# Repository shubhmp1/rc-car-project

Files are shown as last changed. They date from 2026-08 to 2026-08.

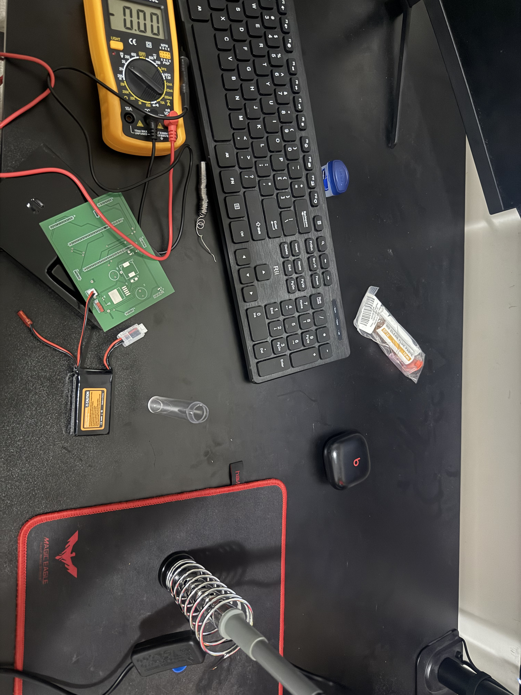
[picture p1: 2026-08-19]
media/build-photos/IMG_1891.jpg

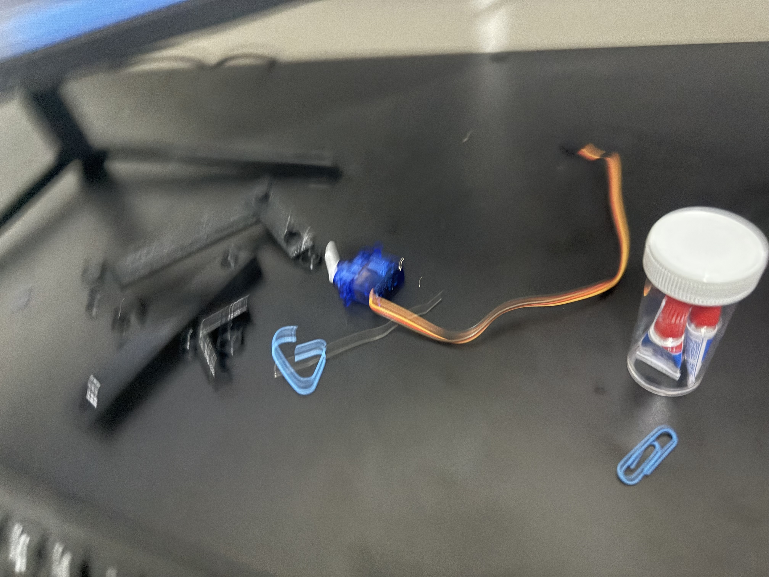
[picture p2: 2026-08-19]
media/build-photos/IMG_1993.jpg

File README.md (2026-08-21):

# Dual-ESP32 RC Car: Custom PCB, 3D-Printed Chassis, With Standard Driving and Auto-Driving Modes

A fully custom-built RC car, designed from scratch: hand-routed PCBs, 3D-printed chassis and wheels, and firmware for two ESP32s talking over nRF24L01 RF. Built solo from schematic to final assembly.

Final car
<!-- swap in your best final-photo filename above -->

---

## Why I built this

Going into engineering, I felt lost, since there are so many different paths (mechanical, electrical, software, embedded) and so much to learn that it was hard to know where to actually start. So instead of trying to learn everything separately, I picked one project that would force me to touch all of it, end to end: CAD, PCB design, firmware, RF communication, sensors, and 3D printing.

Every single one of those was a first for me. I'd never designed a mechanical assembly, never laid out a PCB, never written embedded firmware for a microcontroller, never worked with RF modules or these sensors before this project. I learned all of it here, from scratch, because I wanted proof (mostly to myself) that I could pick up any of these disciplines if I actually committed to it.

And I picked an RC car specifically because outside of computers, cars are what I love most. This project let me combine both.

---

## Demo

**Video:** _[YouTube link coming soon]_

<!-- once uploaded, replace with: [![Watch the demo](docs/images/thumbnail.jpg)](https://youtube.com/your-link) -->

---

## What it does

The car runs on two ESP32s (one in the handheld remote, one on the car), communicating over **nRF24L01 RF**. The remote has a joystick, a TFT display showing speed/mode/sensor data, and three mode buttons with illuminated LEDs.

**Modes:**
- **Standard Driving Mode (done):** manual driving. Joystick controls throttle (with exponential curve, deadzone, and slew-rate limiting) and steering.
- **Auto-Driving Mode (done):** a front-facing ToF sensor slows/stops the car as it approaches obstacles, while two IR line sensors keep it centered between track markers (tested using black tape "lanes" on the ground).
- **AI Gesture Mode (planned, not built):** connect the car to a PC over WiFi and drive it using hand-gesture recognition from a model running locally. Documented as a future addition in the [build notes](docs/Rough_Dev_Journal_And_Notes.docx).

## Hardware

Full parts list and exact values are in the [Specs](#specs) table below. At a high level: two ESP32s (one per board), custom Altium PCBs for both the car and remote, a brushed DC gear motor through an L298N driver, servo-based Ackermann steering, a ToF sensor for obstacle detection, IR sensors for line tracking, and a 3D-printed chassis/wheel set iterated across several print revisions.

## Specs

| Spec | Value |
|---|---|
| MCU | 2× ESP32 (one in the remote, one on the car) |
| Communication | nRF24L01, 250kbps, with ACK-payload telemetry back to the remote |
| Motor | GA12-N20, 6V, 200RPM, all-metal gearbox, 3mm shaft |
| Motor Driver | L298N |
| Steering | Standard positional servo, Ackermann-style linkage |
| Joystick | PS2-style dual-axis breakout module |
| Display | Waveshare 2.4" SPI LCD, 240×320, 65K color |
| Obstacle Sensor | VL53L1X ToF (long-range mode) |
| Line Sensors | 2× TCRT5000 IR reflectance sensors |
| Chassis / Wheels | 3D-printed (PLA), iterated through multiple print revisions |
| PCBs | Custom, designed in Altium (one for the car, one for the remote) |

## How it works

**Communication:** the remote and car each run their own ESP32, talking over an nRF24L01 RF link. Every ~50ms the remote sends a small packet containing motor speed, steering angle, current mode, and (in auto-driving mode) an armed flag and target cruise speed. The car replies on the same exchange using nRF24's ACK-payload feature, sending back live sensor readings (IR states, ToF distance, current speed, and status flags) so the remote's display can show what the car is actually doing in real time, not just what was last commanded.

**Standard driving mode:** joystick input is normalized, run through a small deadzone, shaped with an exponential curve (so small stick movements give fine control, large movements ramp up quickly), and slew-rate limited before being sent, so the motor doesn't jump instantly between speeds or slam through zero when reversing.

**Auto-driving mode:** the car ignores direct joystick input entirely and drives itself off two inputs: two IR sensors on the underside detect track-edge markers and nudge steering back toward center when either sensor sees the line, and a ToF sensor up front continuously calculates a dynamic safe-stopping distance based on the car's current speed (faster speed → longer required stopping distance), slowing or fully stopping the car as it approaches obstacles. The remote is used first to set a target cruise speed, then the car handles both throttle and steering on its own within that mode.

**Displays and modes:** the remote's screen (driven over SPI) shows different HUDs depending on the active mode, live speed/direction/steering in standard mode, or live sensor telemetry and braking status in auto-driving mode, so you can see what the car's sensors are reading even while it's driving itself.

Full firmware for both boards is in [`firmware/`](firmware/).

## Repo structure

```
├── docs/
│   ├── Rough_Dev_Journal_And_Notes.docx   ← full unfiltered build log/notes
│   └── images/                             ← screenshots & progress photos
├── hardware/
│   ├── cad/           ← final STEP files (chassis, wheels, mounts)
│   ├── pcb/            ← Altium projects + gerbers for both boards
│   │   ├── RC_Car/
│   │   └── RC_Remote/
│   └── 3d-print/       ← .3mf print files (all iterations kept)
├── firmware/
│   ├── Car/            ← car-side Arduino sketch
│   └── RC/             ← remote-side Arduino sketch
├── media/
│   ├── build-photos/   ← progress photos throughout the build
│   └── final-photos/   ← finished car
└── README.md
```

## Build photos

A few shots from along the way. See [`media/build-photos`](media/build-photos) for the full set.

<!-- Consider dropping 2-3 of your favorite in-progress photos inline here, e.g.: -->
<!-- ![Soldering the PCB](media/build-photos/photo1.jpg) -->

## Lessons learned

Pulled from the full [build journal](docs/Rough_Dev_Journal_And_Notes.docx), short version:

- **Bluetooth's signal backlog caused an infinite loop** in early remote-to-car communication. Switched to nRF24 RF instead, which was far more reliable for this use case.
- **PWM-driven motor control glitched under per-loop calculation load:** the ESP32 couldn't keep up doing full throttle/LED calculations every cycle. Fixed by throttling the calculation rate (~25Hz instead of 100Hz) and reducing floating-point math in the hot path.
- **Motor driver testing with a bare BJT/MOSFET failed:** couldn't draw enough current. Confirmed the need for a proper motor driver IC (L298N) rather than a hand-built switching circuit.
- **A GND/5V short during power-supply assembly** was a good reminder to double- and triple-check polarity before powering up a new board, since one bad connection can take out multiple components at once.
- **Hand-soldering fine-pitch parts (buck converters, ESP32 headers) without hot air or flux paste** led to several repeated attempts and a few damaged boards/pins, showing the value of having the right soldering tools before starting dense PCB assembly.
- **PCB trace width mattered more than expected:** signal traces at 0.2mm, power at 0.5mm, and battery lines at 0.8mm, with careful separation between noisy traces (motor lines) and sensitive ones (RF module) to avoid interference.
- **3D-printed part tolerances needed iteration:** the first wheel rim print was a couple mm undersized on outer diameter despite correct shaft/width dimensions, so it took a second revision to dial in.
- **Debugging RF instability came down to reworked solder joints:** several intermittent sensor/module failures traced back to damaged pins from desoldering, ultimately solved by fresh ESP32 boards rather than continuing to chase individual pin issues.

## Status

Core build (standard driving mode + auto-driving mode) is complete and working. AI gesture mode is a planned future addition; see the notes for early thinking on that.

## License

[MIT](LICENSE). Feel free to reference, fork, or build on this. Attribution appreciated.

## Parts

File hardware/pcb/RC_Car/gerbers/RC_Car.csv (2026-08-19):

Line # | Name | Description | Designator | Revision ID | Revision State | Revision Status | Quantity | Manufacturer 1 | Manufacturer Part Number 1 | Manufacturer Lifecycle 1 | Supplier 1 | Supplier Part Number 1 | Supplier Unit Price 1 | Supplier Subtotal 1
1 | EEUFM1E681 | 680F 25V Aluminum Electrolytic Capacitors Radial, Can 5000 Hrs @ 105C | C1 |  | Not managed |  | 1
2 | EEU-FC1E471 | Capacitor Polarised | C2 |  | Not managed |  | 1
3 | Capacitor 100 nF +/-10% 50 V 0603 | Chip Capacitor, 100 nF, +/- 10%, 50 V, 0603 (1608 Metric) | C3, C4, C5 | CMP-001-00017-6 | Draft | Up to date | 3 | KYOCERA AVX | 06035C104KAT2A | Volume Production | RS (Formerly Allied Electronics) | 06035C104KAT2A | 0.02768 | 0.08305
4 | CDBA540-HF | Schottky Diode | D1 |  | Not managed |  | 1
5 | TLMS1100-GS08 | Red Led, 20mA, 2.1 V, -40 to 100 degC, 2-Pin SMD (0603), RoHS, Tape and Reel | D2 | CMP-007-00030-2 | Draft | Up to date | 1 | Vishay | TLMS1100-GS08 | Obsolete
6 | ESP32 Left Header | 20 Position Receptacle Connector 0.100 (2.54mm) Through Hole Gold | J1 |  | Not managed |  | 1
7 | ESP32 Right Header | 20 Position Receptacle Connector 0.100 (2.54mm) Through Hole Gold | J2 |  | Not managed |  | 1
8 | nRF24 Signals | Headers & Wire Housings .100 Tiger Buy Socket Strip, Square Tail | J3 |  | Not managed |  | 1
9 | nRF24 Power | SSQ Series .100 Tiger Buy™ Socket Strip, Square Tail | J4 |  | Not managed |  | 1
10 | B2B-PH-K-S(LF)(SN) | Male Header, Pitch 2 mm, 1 x 2 Position, Height 6 mm, Tail Length 3.4 mm, -25 to 85 degC, RoHS, Bulk | J5 | CMP-2000-05162-1 | Released | Up to date | 1 | JST | B2B-PH-K-S(LF)(SN) | Volume Production | Arrow Electronics | B2B-PH-K-S(LF)(SN) | 0.14118 | 0.14118
11 | L298N | Headers & Wire Housings .100 Tiger Buy Socket Strip, Square Tail | J6 |  | Not managed |  | 1
12 | Servo Motor | 3 Position Receptacle Connector 0.100 (2.54mm) Through Hole, Right Angle Tin | J7 |  | Not managed |  | 1
13 | Tof Sensor | Connector | J8 |  | Not managed |  | 1
14 | IR Sensor Left | 3 Position Receptacle Connector 0.100 (2.54mm) Through Hole, Right Angle Tin | J9 |  | Not managed |  | 1
15 | IR Sensor Right | 3 Position Receptacle Connector 0.100 (2.54mm) Through Hole, Right Angle Tin | J10 |  | Not managed |  | 1
16 | DR127-220-R | 22µH Shielded Wirewound Inductor 4A 39.1mOhm Nonstandard | L1 |  | Not managed |  | 1
17 | RC0603JR-13150RL |  | R1 | CMP-2000-04317-1 | Released | Up to date | 1 | Yageo Group | RC0603JR-13150RL | Volume Production | Mouser | 603-RC0603JR-13150RL | 0.13841 | 0.13841
18 | Power Switch |  | SW1 |  | Not managed |  | 1
19 | LM2596S-5.0 | SIMPLE SWITCHER® 4.5V to 40V, 3A Low Component Count Step-Down Regulator | U1 |  | Not managed |  | 1

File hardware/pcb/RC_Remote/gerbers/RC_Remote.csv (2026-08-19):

Line # | Name | Description | Designator | Revision ID | Revision State | Revision Status | Quantity | Manufacturer 1 | Manufacturer Part Number 1 | Manufacturer Lifecycle 1 | Supplier 1 | Supplier Part Number 1 | Supplier Unit Price 1 | Supplier Subtotal 1
 | EEUFM1E681 | 680F 25V Aluminum Electrolytic Capacitors Radial, Can 5000 Hrs @ 105C | C1 |  | Not managed |  | 1
 | EEU-FC1E471 | Capacitor Polarised | C2 |  | Not managed |  | 1
 | Capacitor 100 nF +/-10% 50 V 0603 | Chip Capacitor, 100 nF, +/- 10%, 50 V, 0603 (1608 Metric) | C3, C4 | CMP-001-00017-6 | Draft | Up to date | 2 | KYOCERA AVX | 06035C104KAT2A | Volume Production | RS (Formerly Allied Electronics) | 06035C104KAT2A | 0.02768 | 0.05536
 | CDBA540-HF | Schottky Diode | D1 |  | Not managed |  | 1
 | TLMS1100-GS08 | Red Led, 20mA, 2.1 V, -40 to 100 degC, 2-Pin SMD (0603), RoHS, Tape and Reel | D2 | CMP-007-00030-2 | Draft | Up to date | 1 | Vishay | TLMS1100-GS08 | Obsolete
 | ESP32 Left Header | 20 Position Receptacle Connector 0.100 (2.54mm) Through Hole Gold | J1 |  | Not managed |  | 1
 | ESP32 Right Header | 20 Position Receptacle Connector 0.100 (2.54mm) Through Hole Gold | J2 |  | Not managed |  | 1
 | nRF24 Signals | Headers & Wire Housings .100 Tiger Buy Socket Strip, Square Tail | J3 |  | Not managed |  | 1
 | nRF24 Power | SSQ Series .100 Tiger Buy™ Socket Strip, Square Tail | J4 |  | Not managed |  | 1
 | TFT Display | Headers & Wire Housings .100 Tiger Buy Socket Strip, Square Tail | J5 |  | Not managed |  | 1
 | Joystick | Headers & Wire Housings .100 Tiger Buy Socket Strip, Square Tail | J6 |  | Not managed |  | 1
 | B2B-PH-K-S(LF)(SN) | Male Header, Pitch 2 mm, 1 x 2 Position, Height 6 mm, Tail Length 3.4 mm, -25 to 85 degC, RoHS, Bulk | J7 | CMP-2000-05162-1 | Released | Up to date | 1 | JST | B2B-PH-K-S(LF)(SN) | Volume Production | Arrow Electronics | B2B-PH-K-S(LF)(SN) | 0.14118 | 0.14118
 | DR127-220-R | 22µH Shielded Wirewound Inductor 4A 39.1mOhm Nonstandard | L1 |  | Not managed |  | 1
 | MFR-25FBF52-47R5 | Axial Resistor, 47.5 Ohm, +/- 1%, 0.25 W, -55 to 155 degC, 2-Pin THD, RoHS, Bulk | R1, R2, R3 | CMP-009-00058-4 | Draft | Up to date | 3 | Yageo Group | MFR-25FBF52-47R5 | Volume Production | Arrow Electronics | MFR-25FBF52-47R5 | 0.07336 | 0.22007
 | RC0603JR-13150RL |  | R4 | CMP-2000-04317-1 | Released | Up to date | 1 | Yageo Group | RC0603JR-13150RL | Volume Production | Mouser | 603-RC0603JR-13150RL | 0.13841 | 0.13841
 | B3W-9002-Y1N | SWITCH TACTILE SPST-NO 0.05A 24V | SW1, SW2, SW3 | CMP-08834-000016-1 | New From Design | Up to date | 3 | Omron | B3W-9002-Y1N | Volume Production | Mouser | 653-B3W-9002-Y1N | 5.9 | 17.69
 | Power Switch |  | SW4 |  | Not managed |  | 1
 | LM2596S-5.0 | SIMPLE SWITCHER® 4.5V to 40V, 3A Low Component Count Step-Down Regulator | U1 |  | Not managed |  | 1

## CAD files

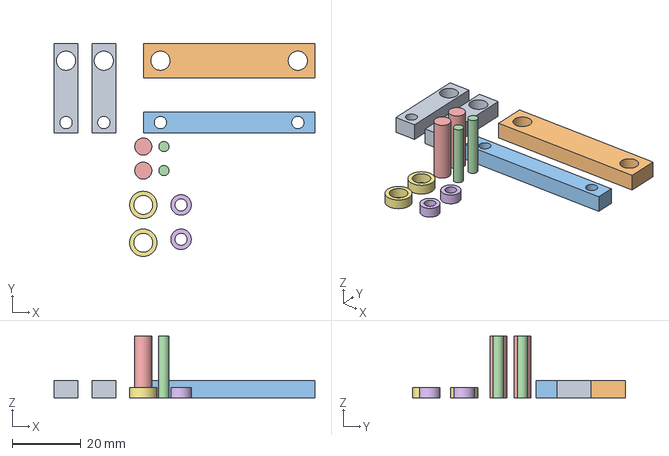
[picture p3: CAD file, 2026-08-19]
hardware/cad/Steering_Mech_V2.stp
76.0 x 62.0 x 18.0 mm

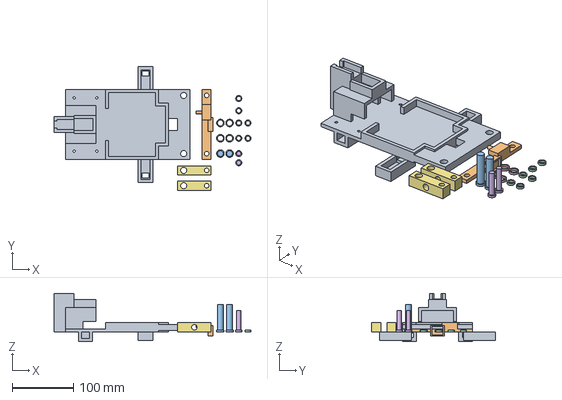
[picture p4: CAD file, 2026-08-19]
hardware/cad/Car_Chassis_V7.stp
322.0 x 202.0 x 79.0 mm

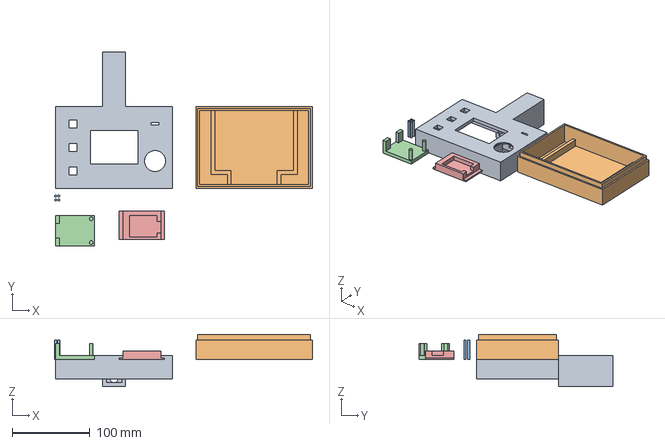
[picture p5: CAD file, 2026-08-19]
hardware/cad/Remote_Cad_V10.stp
331.5 x 249.0 x 67.0 mm

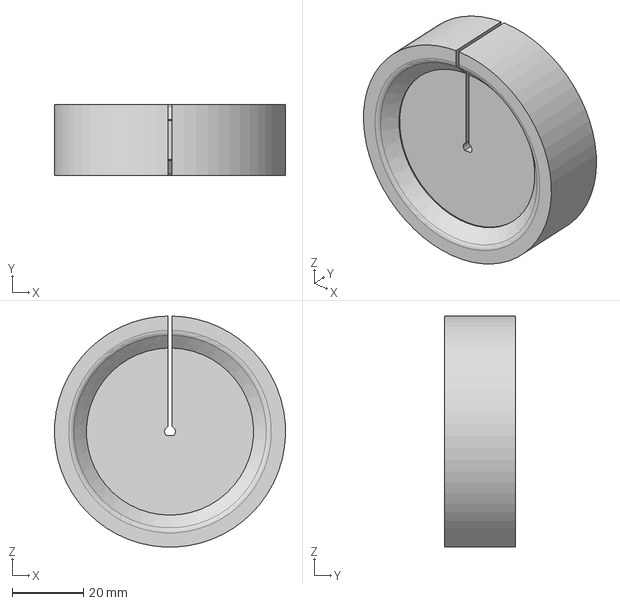
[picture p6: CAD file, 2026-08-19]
hardware/cad/RC_Car_Wheel_Rim_V3.stp
65.0 x 20.0 x 65.0 mm

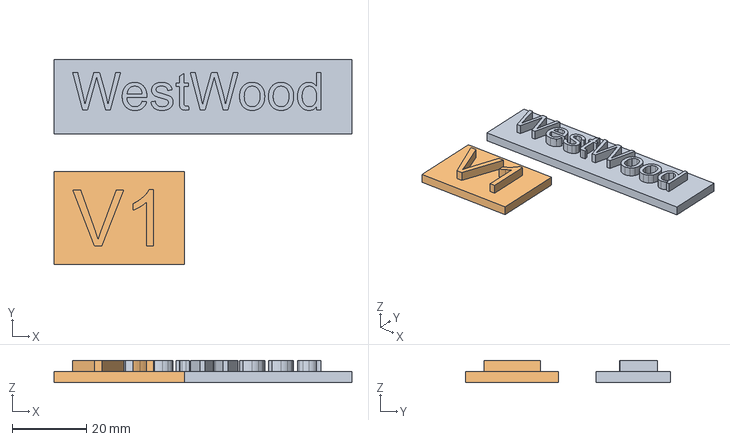
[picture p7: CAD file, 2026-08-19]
hardware/cad/Sign_V2.stp
80.0 x 55.0 x 6.00 mm

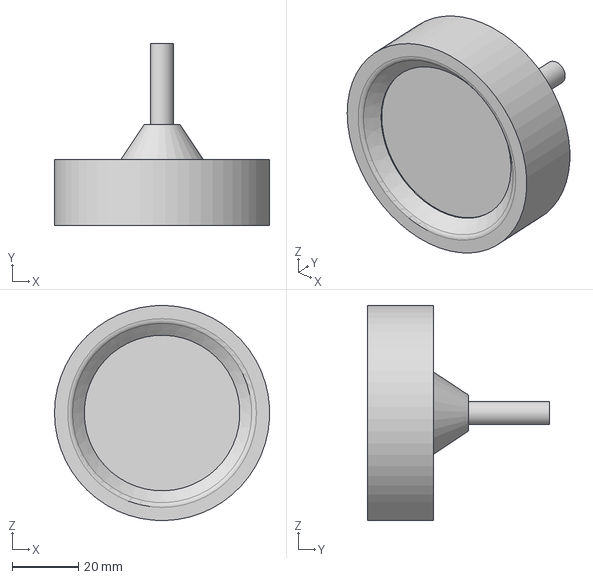
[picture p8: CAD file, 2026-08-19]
hardware/cad/RC_Car_Front_Wheel_Rim_V3.stp
64.9 x 55.0 x 65.0 mm

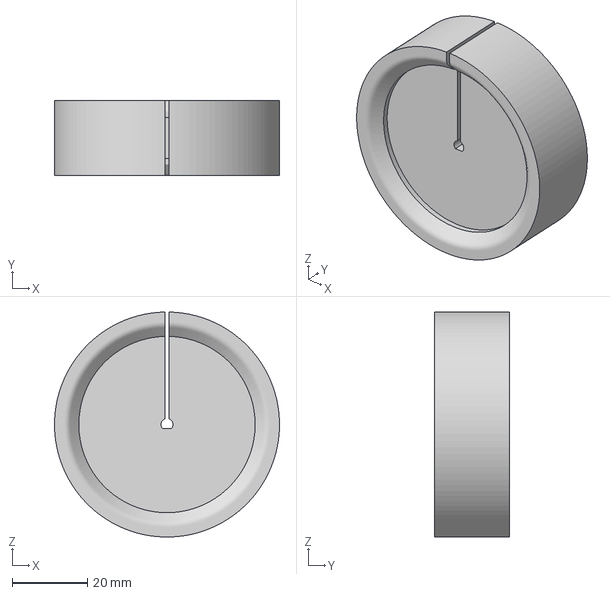
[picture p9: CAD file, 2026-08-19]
hardware/3d-print/RC_Car_Wheel_Rim.3mf
60.0 x 20.0 x 60.0 mm

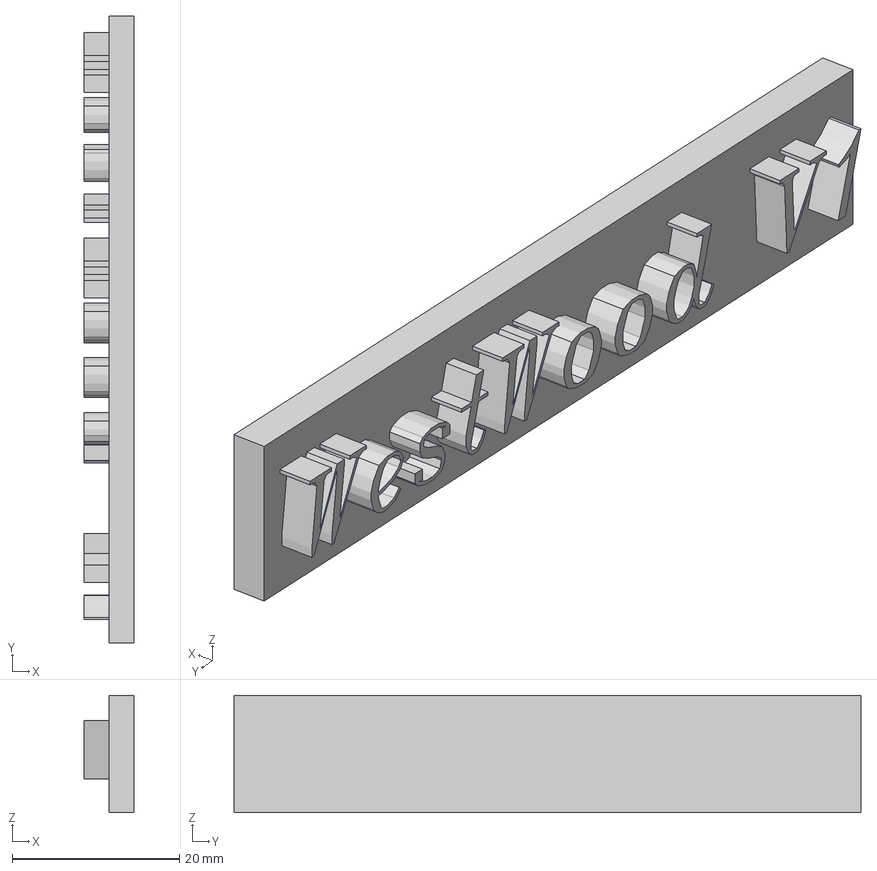
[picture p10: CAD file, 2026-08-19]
hardware/3d-print/Sign.3mf
6.00 x 75.0 x 14.0 mm

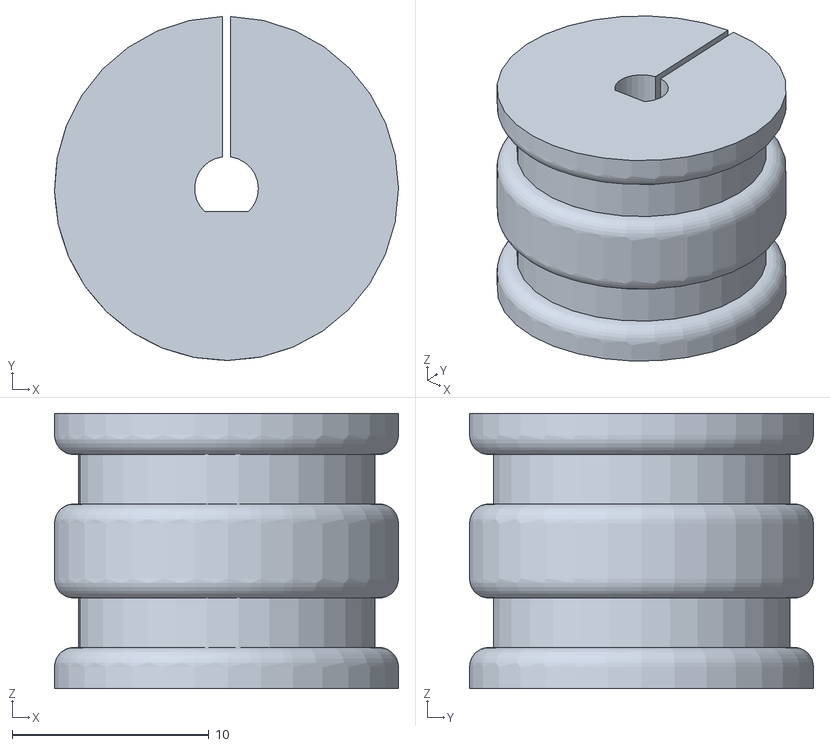
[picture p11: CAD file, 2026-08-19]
hardware/3d-print/double_wheel_14.stl
17.5 x 17.5 x 14.0

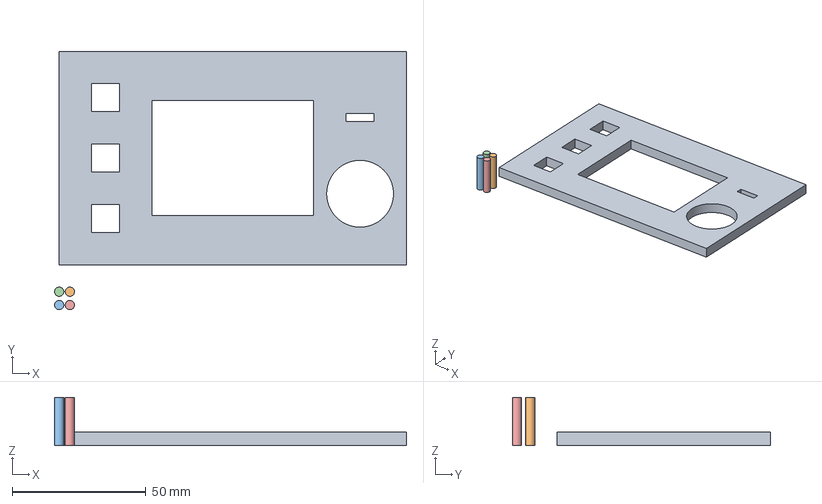
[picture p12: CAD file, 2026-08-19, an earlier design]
hardware/3d-print/Remote_Cad_V3.3mf
131.8 x 96.8 x 18.0 mm

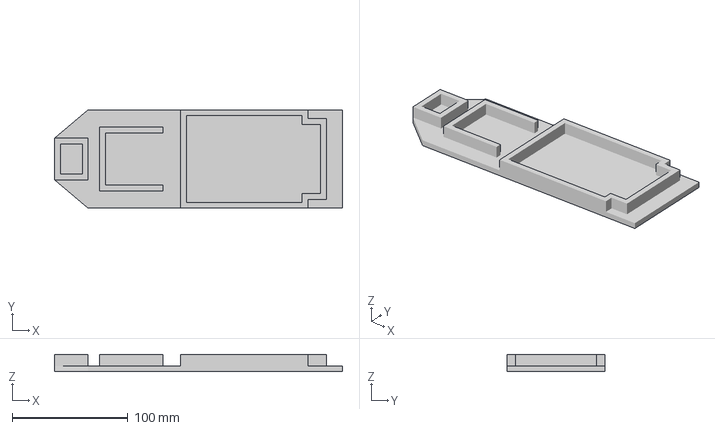
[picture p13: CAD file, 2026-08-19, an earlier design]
hardware/3d-print/Car_Chassis_V1.3mf
249.0 x 85.0 x 15.0 mm

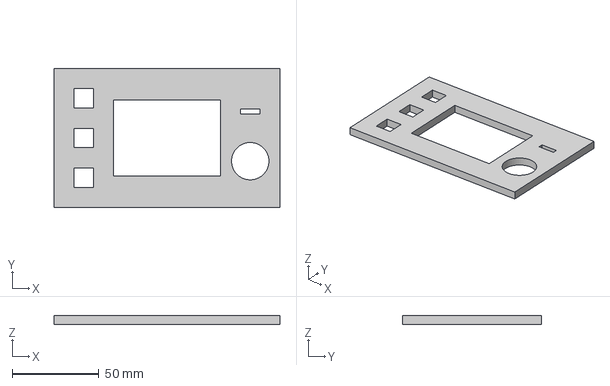
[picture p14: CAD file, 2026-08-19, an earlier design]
hardware/3d-print/Remote_Cad_V2.3mf
130.0 x 80.0 x 5.00 mm

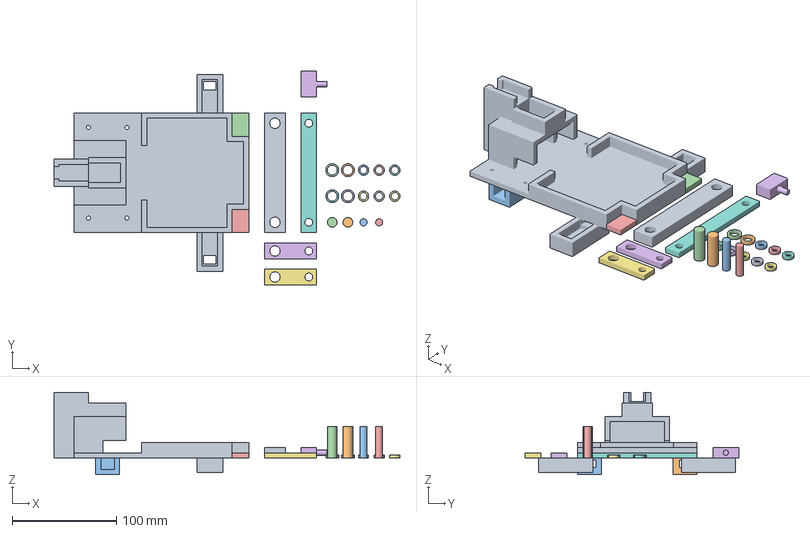
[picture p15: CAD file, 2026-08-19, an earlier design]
hardware/3d-print/Car_Chassis_V5.3mf
332.0 x 205.0 x 79.0 mm

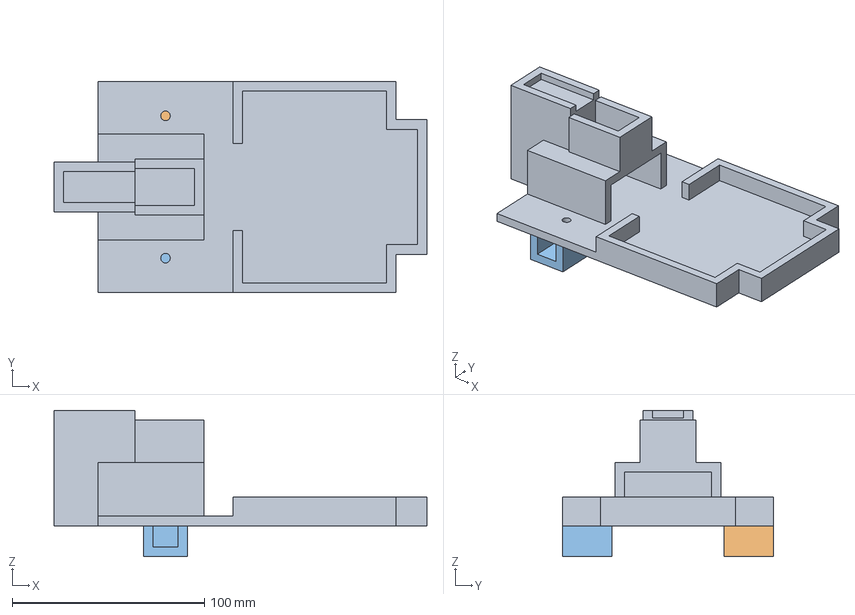
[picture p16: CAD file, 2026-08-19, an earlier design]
hardware/3d-print/Car_Chassis_V2.3mf
194.0 x 110.0 x 76.0 mm

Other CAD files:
hardware/3d-print/Car_Chassis_V8.3mf
hardware/3d-print/Remote_Cad_V11.3mf
hardware/3d-print/Steering_Mech_V3.3mf
hardware/3d-print/Steering_Mech_V1.3mf
hardware/3d-print/Car_Chassis_V3.3mf
hardware/3d-print/Car_Chassis_V4.3mf
hardware/3d-print/Car_Chassis_V6.3mf
hardware/3d-print/Car_Chassis_V7.3mf
hardware/3d-print/RC_Car_Front_Wheel_Rim_V1.3mf
hardware/3d-print/RC_Car_Front_Wheel_Rim_V2.3mf
hardware/3d-print/RC_Car_Front_Wheel_Rim_V3.3mf
hardware/3d-print/RC_Car_Wheel_Rim_V2.3mf
hardware/3d-print/RC_Car_Wheel_Rim_V3.3mf
hardware/3d-print/Remote_Cad_V1.3mf
hardware/3d-print/Remote_Cad_V10.3mf
hardware/3d-print/Remote_Cad_V4.3mf
hardware/3d-print/Remote_Cad_V5.3mf
hardware/3d-print/Remote_Cad_V6.3mf
hardware/3d-print/Remote_Cad_V7.3mf
hardware/3d-print/Remote_Cad_V8.3mf
hardware/3d-print/Remote_Cad_V9.3mf
hardware/3d-print/Sign_V2.3mf
hardware/3d-print/Steering_Mech_V2.3mf

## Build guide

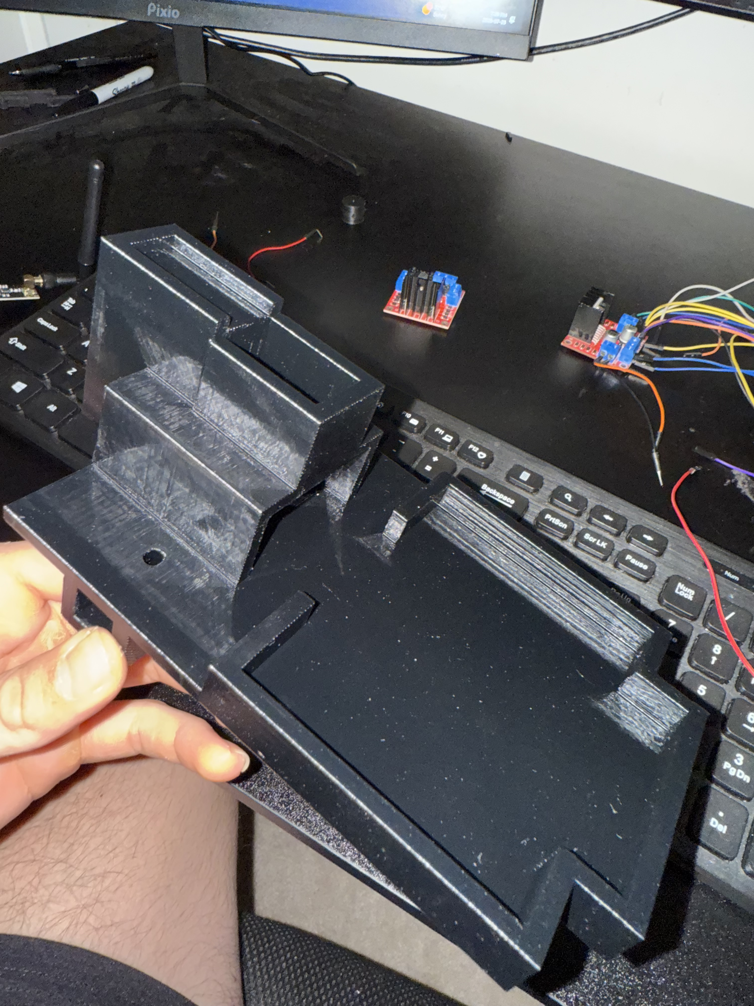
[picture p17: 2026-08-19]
media/build-photos/IMG_1975.jpg

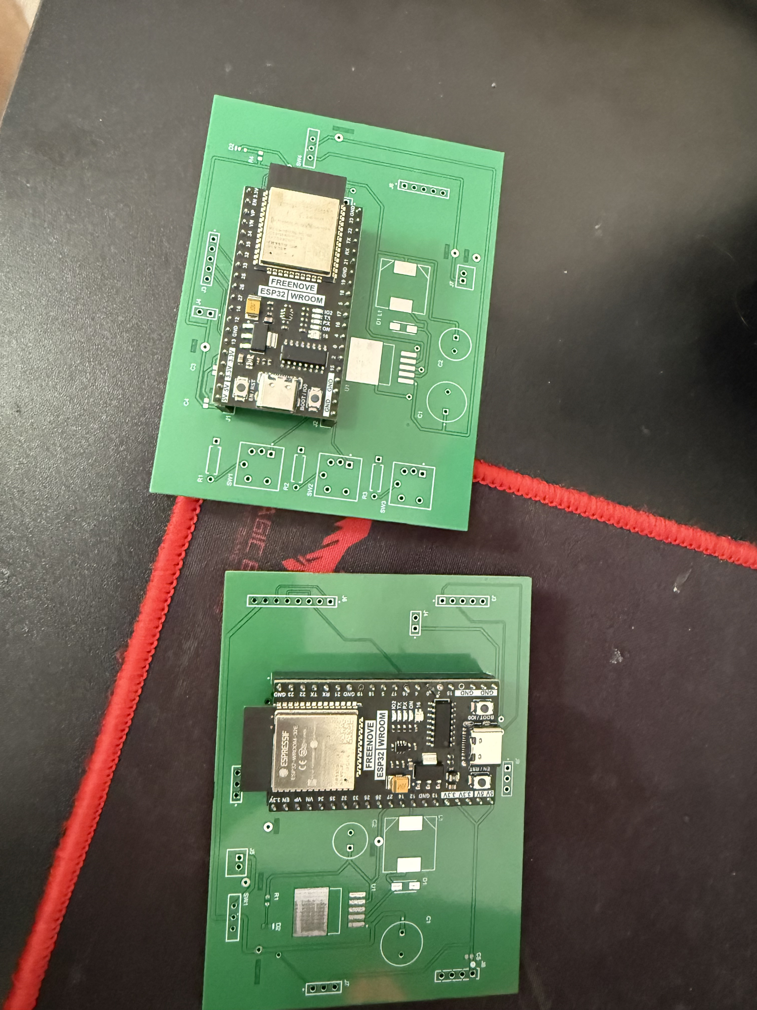
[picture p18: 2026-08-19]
media/build-photos/IMG_1922.jpg

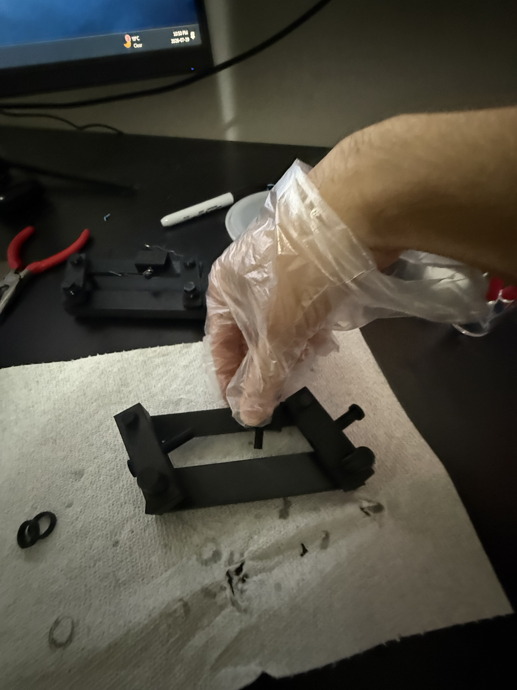
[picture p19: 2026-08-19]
media/build-photos/IMG_2006.jpg

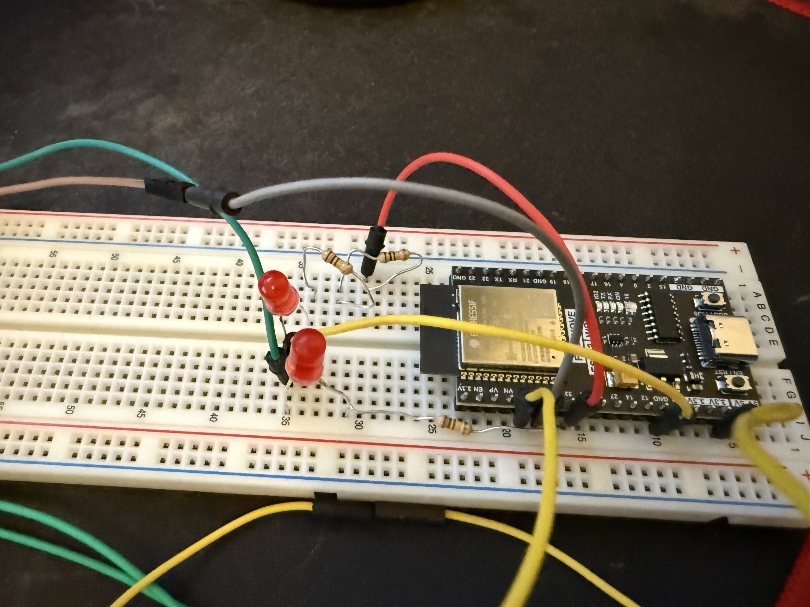
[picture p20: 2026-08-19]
media/build-photos/IMG_1554.jpg

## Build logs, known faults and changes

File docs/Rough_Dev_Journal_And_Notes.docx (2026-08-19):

Two ESP-32 With WIFI/BLUETOOTH/RF CONNECTIVITY

- Turning will be done, by simple servo motor changing direction in front, could possibly do pulse width modulation I do not know exactly how the angles on them work to make micro ajudsments, I would use differential but not required for this simple of design.
- Making an h-bridge PCB to use a more powerful battery to a good motor, also use pulse width modulation to allow the motor to have a variety of speeds
- If i use a bigger battery, im gonna have to make power supply PCB to the esp32
- ESP-32 going to use a communication protocol, thru wifi/bluetooth, from controller to car
- The rc can have the joystick, a button for honk, a screen for speed, a screen for battery percentage.

I wanna eventually make it so I can connect a camera to it, i can sit in my room then use a model to move it based on something the models detects me do, like put specific hand geistures or something. This would require me to do a WEB server, and me locally running a python script for the model

- Im gonna have to CAD the the controller and car, preferably make it like an M8.

Notes:

- For the joystick keep pins to left, so bottom right will have 4095.
- Servo motor right 0deg, and left 180 deg
- When implementing the servo motor i ran into a hardware limitation with the esp32 cpu being to slow for doing all the calculations for each loop cycle meaning the led, the throttle control, goes super slow. To solve this im trying to make it so you do not do those calculations every loop, not 100 times a second maybe lik 25 times a second, and also tried reducing floating point number calculations
- I tried to do bluetooth, but its buggin havent fixed it yet, like the pwm signal doesnt work bec of a backlog forming of signals from the rc that causes the car to be in an infinite loop. I am going to try a handshake approach tomorrow, where i send a signal back when a message is received and only then i send another one. I am going to have to account for error messages as well, parallel processing didnt work, but chat saying this solution i thought of could work
- Shrey told me to try using RF technology to do the signal transfer between the controller and the car, try that
- Also im really thinking that i should still stick this stage more, because im thinking of adding autonomous driving, done by connecting the car thru wifi to my computer by like a switch on the remote controller to make it in autonomous mode
- ebyte lora, long range mad slow, or nRF24, short range mad fast.
- nRF240I over the the other one is communicated using spi from the esp32
- RF over bluetooth, PWM being super buggy, and i had to fix by making it occur every certain time frame instead of each loop
- Changed from cubic to quadratic rate for the motor
- Debounce required for the button to show westwood animation.
- Im adding a third mode with another button thats gonna do ai hand signal moving using wifi, no more hardware needed other than extra button, can implement after car is made physically.
- Add LEDS ontop of the button to indicate current mode.

Timeline

Throttle:

- Using PWM to control speed, ESP32 has built in function
- Gonna make the control exponential
- Add tiny deadzone for the joystick
- Have to add a function for ramping or slew rate limiting.
- Figure out reverse direction with one PWM pin, and one direction pin, the driver board would have a way where i can switch voltage, kind of like switch 2 from 2ei4 project 2, to let current flow thru the motor opposite direction
- LED indicators

How to test:

- Two LEDS, when going forward one will do the thing with voltage = 0 at center, and then the other will do in opposite direction. ✅
- Add tiny deadzone ✅
- Make an exponential ✅
- Make a function for ramping or slew rate limiting✅
- Change the code for the motor and test that now. I TRIED TESTING THE MOTOR, WITH A SIMPLE CIRCUIT I TRIED WITH THE BJT AND THE A MOSFET FROM THE 2EI4 KIT WITH VCC= 5V AND BASE OR GATE BEING THE PWM SIGNAL, BUT IT WOULDN’T WORK AS IT COULDN’T DRAW ENOUGH CURRENT.
- The way I made it now is one LED acts, as the PWM signal, and the other the direction, as thats all the esp32 is providing to the eventual motor driver, further testing to be done with the motor driver and what i have should work.

Quick Changes For Motor:

- (Currently Have two PWM PINS AS IM WORKING WITH LEDS RN, BUT THIS IS QUICK FIX, IN THE IF STATEMENTS FOR FORWARD AND REVERSE CHANGE THE DIRECTION PIN AND HAVE PWM FOR ONE PIN ONLY)
- May have to account for Minimum motor start duty Many motors won’t move until ~20–30% PWM.

Steering:

- Positional servo motor starting at center moves left and right based on joystick x direc movements.
- Add tiny deadzone, grab function from throttle
- Make an exponential, grab function from throttle
- Make a function for ramping or slew rate limiting, grab function from throttle, but make it so the step is much much bigger and only one value not two as there isn't the same mechanical issues for moving left right that the throttle has.
- Im doing like a ackerman style mechanism, just printed something basic testing thing off top my head to see how it would look conceptually
- I know there is math I am going to have to do to determine the ackerman proportions and what not, and aslo need to properly understand why I need it, to a degree I do as both wheels do not turn at same angle, but you know what I mean

Remote Control:

- Use uart for sending the numbers over,
- Make it so i can display throttle speed, the normalized value as a percentage
- A XXX X XX B. HAVE THE RC LOOP RUN WITH A DELAY OF 50 MS FOR TESTING, MAIN ISSUE IS THE BACKLOG OF INFORMATION
- Im going to try using RF signals
- Have a switch that lets it enter autonomous mode, which can look at the road on the ground for example i can have the lanes lines, the controller can have right and left signaling things that let the car turn automatically, go straight, and auto stop if something comes infront of it
- Im using the RF module now, it is used with the breakout adapter, an you need to use more than 3.3V, the thing will regulate, it needs current
- I have a screen that has a display, an animation and what not
- Added three mode buttons using internal pull-ups: SW1 on GPIO19 for RC mode, SW2 on GPIO21 for semi-auto mode, and SW3 on GPIO22 for AI mode.
- Added three mode LEDs from the schematic: GPIO15 for RC mode, GPIO33 for semi-auto mode, and GPIO12 for AI mode. Only the LED for the current mode turns on.
- Remote now starts in default RC mode. Normal joystick driving only works while RC mode is selected.
- Semi-auto mode and AI mode are placeholders for now. Pressing their buttons switches modes and lights the correct LED, but they do not run driving logic yet.
- Added debounce logic for the three mode buttons so one press only registers once.
- Added safety stop on mode change. Before switching modes, the remote sends neutral motor and steering packets to stop the car and reset steering to center.
- Added sensor telemetry receiving through nRF24 ACK payloads so the remote can receive data back from the car.
- Added mode 2 sensor display screen showing left IR value, right IR value, and VL53L0X distance.
- Mode 2 now keeps the car stopped and sends neutral packets while requesting sensor telemetry.
- During startup/replay animation, all mode LEDs turn off. After animation finishes, the current mode LED turns back on.
- Existing remote joystick, RF, display, mode button, and mode LED pins stayed the same.

Semi-Auto Driving:

- I want to add semi auto driving, use a tof sensor in the front of the car to slow the car down or obstacle to stop, and IR/ LineTracker sensor to stay in the middle of the road. I will put down Black Tape on the ground left and right like the road to demo.
- I will add the sensors to the car esp32, and button to toggle normal drive and semi auto drive on the Remote control, add logic later after assembly.
- Just add the sensors to the esp32 and make the functionality of the toggle button make it so the car just sends the readings to the remote and simple display, to see if the sensors work correctly, as proper logic can be written after assembly, and to check if the nrf24l01 can act as transceiver
- The tof sensor can just have some type of logic to calculate speed to keep distance in front, and if the distance keeps getting less and less instead of staying a number that I pick, like a threshold, then the car keeps slowing down and down until full stop.
- The car gets steering based on the IR/ LineTracker sensor that faces on the ground to check whether close to the road or not if the steering correction, and also if both sides see road borders, the black tape, then the car stops.
- I want to make it so when i click the button, i can use the joystick to determine speed, and than i could click the joystick button at that state to initiate it
- HAVENT GOTTEN HERE, BUT MAKE SURE THE ESP32 DOES A PID CONTROLLER ALGORITHIM FOR THE STEERING CONTROL
- Added two TCRT5000 IR sensor readings for future line/object detection.
- Added VL53L0X ToF distance reading for future obstacle distance measurement.
- Semi-auto mode does not drive yet. It only displays sensor readings and keeps motor/steering neutral.
- Car sends sensor readings back to the remote using nRF24 ACK payloads.
- Bro the tof sensor being so weird, its not reading data for some reason ideky.
- The speed of the ack send, the sensor readings I can change to make faster later when working on the code for that one.
- Bro the difference was VL53L1X is the part I had and I was trying to use VL53L0X library

AI Signal Mode:

- Using an ai model i can use hand gestures to move the car, super simple, doesn't need any other hardware other than an extra button
- Can do logic after car itself is built like the semi auto driving mode

V

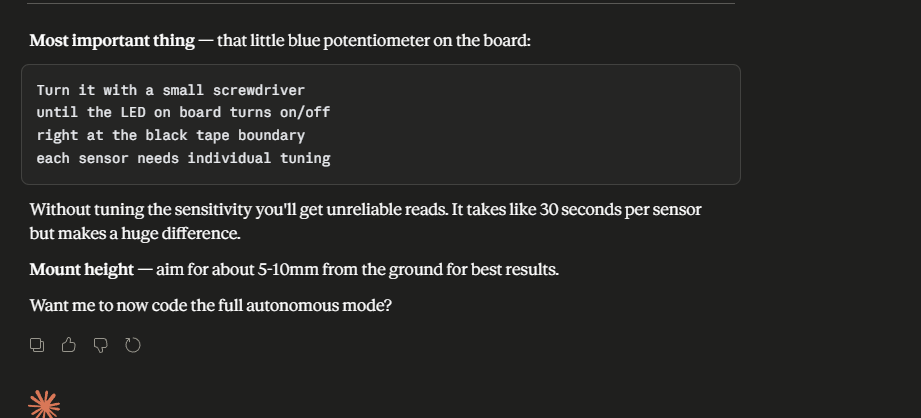
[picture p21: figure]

3D PRINTING TIRE RIMS:

- I need to custom 3d print the tire rims o the motor could connect to the tires, V0.
- First thing i printed online copy https://www.thingiverse.com/thing:3284612, and printed to check if it fit than will make my own and measure the tires and such.
- Measurements were taken using the Caliper I 3D printed
- I printed one using chatgpt recommendations, the whole for d shaft was perfect, the width side length perfect for the inner and outer parts of the rim, however the overall diameter felt a couple mm too small, going to reprint with slightly bigger one and than try again. I used simpler print that doesnt take too long, like the infill, when printing the real wheels going to make infill like 70% but for this purpose its fine, and some other factors better maybe.
- V2 worked, its perfect, all its missing is a design, which I can get to, after adding all the sensors to esp32.
- After sensors, plan is to make Sketch of what the car will look like, and any branding I want to add, so I can add touches to the wheel design as well
- Print V3, the one with the designs and what not, before a final print
- REMEMBER I DID THE SKETCHES ON MY IPAD

REMOTE CONTROL CAD:

- Trying to figure out how I should go about coding the parts to fit the joystick and screen onto
- They both have holes on the corners that maybe like a stick could go into to keep them in place, perhaps with glue ontop of that.
- I was gonna look at how the xbox and ps4 controllers keep the joystick free to move with it being inside completely

Design Choices For CAD:

PCB:

- Was originally gonna print driver board, have the rough sketch design but used prebuilt for each of use.
- Working on the rc schematic right now, everything is female headers.
- The three buttons are gonna be illuminated themselves instead of 3 buttons 3 leds, so the button pressed its mode is active, the led will be on.
- I have to use B3W-9002-Y1N, which is yellow as the footprint model and what not for the other colours I want potentially like green, white or red do not exist, so it will have to do until I order parts where I just swap out which colour I want.
- I only have hand iron, so I had to restart alot of the parts, like the buck converter, as they require flux paste or other ways like the hot blowing gun to get soldered, which im not gonna put more money into right now. This means I got parts that would let me do the hand soldering.
- When doing the PCB layout for the esp32 header pins, i needed to measure the inside part of the esp32 find that distance, and thats the distance between the two headers, 22.92mm gotten from subtracting the male header pins width times two from the total width
- Had to make changes in the schematic after the pcb layout was done, leaving 3-5mm space on the edge, the gnd 3.3V pin was wrong place around in the joystick header, the tft display is also wrong, the buttons resistor I changed from 68 to 47 ohms, the cathode of the LED was 3.3V which i changed to gnd
- After doing that and updating the schematic I went to routing, Im just learning as am going, and making sure I soke up as much knowledge as I can. The routing for example I keep asking Claude which I think is good, Many imagine all these notes on obsidian, I need to get on it super soon brodigy.
- Its saying for signals 0.2mm, power(5V, 3V3) 0.5mm, and VBat 0.8mm.
- Multiple layers, for traces separated by the fiberglass insulator in the middle. Assuming more complex boards will have way more layers.
- PCBs were pretty simple, in the process of shrey and hamza looking at them, memorable things were just making sure certain traces and layout parts were away from one another to ensure there wasn’t noise, like the motor from the nrf module.
- Traces were different sizes based on power, battery, and signals. Like 0.5mm, 0.8mm, 0.2mm.
- So the pcb came and the stupid esp32 doesnt fit perfectly, we gonna see whats gonna happen if the part comes and I solder it, but I might just use wires bec the wait time is so long, for now,
- I did the switch and power supply, excluding light up led, part and i accidentally short circuit the gnd and 5v output, oops, the thing was so hot and gave me a horrendous reading, luckly I fixed it, the solder of the pins were touching, thank goodness. Im getting 4.95V output, hopefully enough for the esp32
- Also i used my second pcb for the car, the voltage converter was impossible to stick using the solder so i just took a fresh one and it worked
- The leds both got cooked while soldering, to see if solder is going thru for the remote the button led and display should indicate it, for the car ill put the normal led and if anyhting i could use the multimeter
- I think this is some up the most frustration ive ever felt doing anything, not even the pokemon ascii project got me like this, all my fingers screwed, and now i screwed my thumb, i cant use it for some time now, thank god i had extra wires, i only need to desolder the motor driver, and the two ir sensors for the car, and just the power pins for the remote
- I forgot about the 5v input for the motor driver, i remembered if i add the jumper back then potentially it can internally handle the 5V step down, last case scenario i just solder that wire to a 5V pin from the esp32
- I need to solder 3 wires remote rf module, 6wires total for both ir sensors combined, and 4 for tof sensor
- Bro i got the male headers for everything off, but i did too good of a job with the tof sensor, the hole via came out and i fried the board :`), im gonna grab it from, aathi, naiyar, or mahi and watch a video on easy way to remove them
- So i tried using the esp with just wires, so doesnt work at all, im gonna solder the esp straight onto the board,
- The leds do not work anymore, so i am getting rid of their functionality, say the third button is future implementation for another mode, like imagine a full automatic with camera and everything mode type of thing and to save time im not doing it anymore.
- Im using the 20 pins connecters now and got the esp32s onto the pcb, the way im doing is using the cable front he computer, ill implement one feature at a time nd see if they work consistently then move on, starting with the remote buttons
- So im back to testing using the arduino ide, the things that dont work are the tof, the two irs, and the one nrf, my best guess is taking the solder pins out screw them, so i have one nrf still ill change it out and see if works, hopefuly it does, the tof ill grab from naiyar, and the two ir modules probably go back to sayal electronics tomorrow and buy the pins as well, but atleast everything other than that works, thank god. Hopefully after that i can put the 5V thing onto the pcb from the other one, and all the pcb stuff works by tomorrow.
- So i switched out the stupid nrf and it still doesnt work. What im doing right now is i took the esps off the pcb, and individually testing with new pins going to the old pins, the assignments for the nrf module, and seeing which pin is causing the issue, since im not using leds anymore i could possible use one of those for the nrf for the remote and the car just pray it works.
- Esp 32 with longer stick soldered on has pin 13 that doesnt work, and thats the only pin that doesnt work, once i come back from picking up the ir module and some header pins i will see if i can use that specific esp for the remote, checking if the pins thats needed in the car and remote are fine and vice versa, then seeing if i could use the button led pin.
- Im switching pin 13 for 33 on the remote pcb, and button 1 19 ill try soldering on it, but if i cant its gonna be pin 15
- My tof sensor on the pcb is vcc is 5v but my vcc is 3.3, im gonna use the via to test 3.3 volts, all the senors work tho, so what i need to do, is change the pins for the button1 and pin 13, also for 3.3V into the tof sensor, those fixes should make it so those three things work.
- Solder pin into 33, 15 on remote, and pin into 3.3V via, change the code so instead of pin 13 is 33, and instead of 19 its 15. Im hoping all the other pins work so that when i connect it up the esps work bec i think originally i had the esps on opposite boards.
- Bro right before soldering pin 18 fell out for the remote which is used for the display other wise, if that display doesnt work im gonna use the last remote led button for it, hopefully it still works i just soldered it back on, the stupid solder hole for the ir sensor with piin 16 is gone on the pcb so i soldered directly onto the pin sticking on the underside of the pcb, i think i should be good to test it now, but ill take a break first.
- Bro screw this im buying two new esps, the broken one is acting up right now, im gonna just use the new ones, this is good tho im learning so much tho on what not to doo next time, im just gonna wait for the new esps and then not even change the pin assignment, hopefully everything works, bec im not going thru the hassle right now to see which pins work or not
- Finally good news bro, with the new esp32 everything works, the nrf module at the start once i first started it was fine, but then started bugging and stopped, prob some wiring issue but everything else works. Im pretty sure with wires i the car pcb, so i could prob put male headers and get it fixed. Finally brother its been a month, ill finish this tommorow, then weekend the remote, and then next monday and tuesday car hopefully, then new week work time get git hub and everything done. If i actually lock in, I can finish all this fast and get the verliog stuff learnt, and risc 5 completed, with the chip and assic board printed from tiny tapeout i need to be done everything by july 24 today is july 16 you got this brother.
- I forgot i need to solder the 5v converter stuff onto the board, ill do that after i fix the nrf module, and then i can do the remote after that.
- So all the technical stuff works, but the nrf module just buggy some times so just reset the car esp each time that happens, i need to solder the 5v stuff on, which i will do after i come back from walmart
- So i did the soldering for the power supply and everything works, but one of the inductors were broken so I had to buy a new one, but the connection worked perfectly
- I spent way more to buy the extra esp32, the extra sensors, and new Inductor, but it was learning experience, i think im done with this part like i just need to solder the new inductor when it comes in, but I will get started on the car CAD, as that will be annoying

Car CAD:

- I'm gonna start with the steering system, then work my way backwards, as the tires are already made, and the rest should be pretty easy you know?
- https://www.youtube.com/watch?v=vlSZeEDv-VY, this the video im gonna do similar to, theres a couple things I need to figure out tho, like the dimensions how big, also what do i want the wheels rotating on, a metal pin or the 3d printed material you know?
- So following the video im making the steering, ive printed the chassis twice and have hopefully fixed everything
- The steering ive printed twice, the metal rod im using the paperclip and we will see if this works
- So the steering works, i just need to make some adjustments as well as the way i would connect to the remaining car and add the way to put the wheels on, i also need a way to hold the sensor, ill try it again’
- So i havent been uopdating this, but ive been doing alot, right now im buying a motor replamcents bec i messed up, but i think it will help with the smaller pwm actually having the car moving instead of the 500 rpm ones im using now, im gonna use 200rpm.
- Holy bro i just fried my esp32, by connecting 5v and the power thing do not do that again but another 35 down the drain holy man, but rrealistically i have to test the speed thing now bec the steering part of auto drive works, after speed thing i check, then the front on driving, meaning the tof sensor part of it, like making it slow down and what not and im done. Today the filament is coming so ill get that printed and get like maybe the joystick super glued on, buttons, and switch, ill ait for the buttons and the rest of the stuff tho just in case
- This life we live in is one stupid life, the rf module was also fried, thank god i had an extra one, i just used that, like cmon bro thats so stupid.

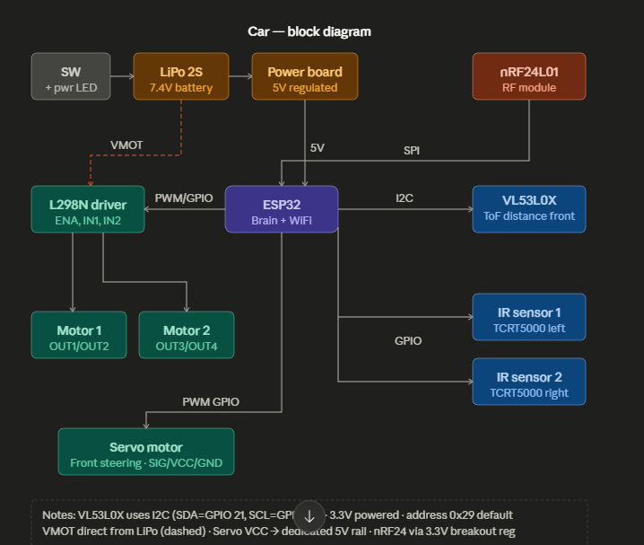
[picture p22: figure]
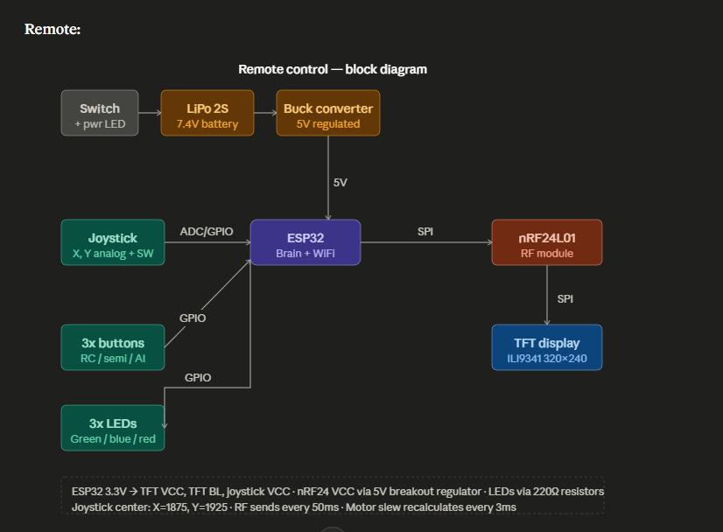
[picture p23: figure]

Hello, so I finished breaboarding my project, but I wanted to make a pcb with some more parts, if you have some time can you look at these block diagrams I got claude to make them for me, and give any advice wht to add, change, how I should go about making the pcb on altium like I think the routeing for the motor will have to be thicker stuff like that, anything for soldering if i should use mostly thru hole, I was thinking using connecters.

Description:

It's a custom RC car built around two ESP32s talking over nRF24L01 RF. The controller has a joystick, a TFT screen showing speed and direction, and three mode buttons. The car has a brushed DC motor through an L298N, a servo for steering, a microwave radar in the front, and two IR sensors on the bottom. There are three modes: regular RC, semi-auto where the radar slows the car for obstacles and the IR sensors keep it between lane markers on the ground, and an AI mode where it connects to my PC over WiFi and I can drive it with hand gestures.

Claude Said This PCB Advice:

For the car power board, stuff that'll save you pain:

Decoupling caps (100nF ceramic) right at the ESP32 power pins and the L298N logic supply — without these you'll get random resets when the motor switches.

A fuse or polyfuse between the LiPo and VMOT. Motors can pull a lot of current on stall and you don't want to cook your traces.

Reverse polarity protection on the LiPo input — a P-channel MOSFET or even just a diode. One wrong connection kills everything.

A dedicated LDO or switching reg for the servo (like an AMS1117-5.0 from the battery rail) with a big capacitor on the output, rather than sharing the main 5V rail. Servo spikes are brutal.

Indicator LEDs on the 5V and 3.3V rails so you know at a glance what's powered up.

Test points on VMOT, 5V, 3.3V, and the SPI lines. You'll thank yourself when debugging.

For the remote, same decoupling caps, and make sure the nRF24 has its own 100µF electrolytic + 100nF ceramic close to its VCC pin — that module is notorious for brownout resets without good bypassing.

## Things to Keep in Mind

- Document what assumptions you are making for when you implement motor driver.
- You might want to log PWM duty to Serial for testing later with motor, so you know the code is producing the correct signals.
- If you simulate, consider virtual “motor current” in code, so you can test braking or direction changes.
- Do NOT power the servo from the ESP32 5V pin. Straight from battery

Pick Motor and Battery ~ Look into possible problems they might have with rest of the design

Design Block Diagram For H-Bridge and get advice from MED-T Lead

Make PCB and ask MED-T Lead for help

PRINT PCB AND TEST WITH MOTOR AND BATTERY

- Power supply for all parts because of current, including RF module, Servo Motor, Motor, I think the joystick should be fine, but might as well

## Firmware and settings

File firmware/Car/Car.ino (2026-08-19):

#include <SPI.h>
#include <nRF24L01.h>
#include <RF24.h>
#include <Wire.h>
#include <VL53L1X.h>

// ============================================================
// PIN DEFINITIONS
// ============================================================
#define ENApin   33   // PWM speed signal to L298N ENA pin
#define IN1pin   32   // L298N IN1 - direction control
#define IN2pin   4    // L298N IN2 - opposite of IN1
#define servoPin 26   // servo signal wire (yellow)

#define RF_CE  27     // controls radio mode (transmit vs listen)
#define RF_CSN 25     // SPI chip select
#define RF_SCK 14     // SPI clock
#define RF_MO  13     // MOSI, ESP32 sends data TO radio
#define RF_MI  35     // MISO, radio sends data TO ESP32 (input-only pin, perfect for MISO)

// ============================================================
// SENSOR PIN DEFINITIONS
// existing car pins above are NOT changed
// these pins are only added for semi-auto sensor readings
//
// TCRT5000 IR sensors:
//   left sensor OUT  -> GPIO34
//   right sensor OUT -> GPIO39
//
// VL53L0X ToF sensor:
//   SDA -> GPIO21
//   SCL -> GPIO22
// ============================================================
#define IR_LEFT_PIN   34
#define IR_RIGHT_PIN  16

#define TOF_SDA       21
#define TOF_SCL       22

// ============================================================
// PWM CONFIGURATION
// motor uses 5000Hz, servo uses 50Hz (standard for positional servos)
// 8 bit resolution = 0 to 255 duty cycle values
// ============================================================
int PWMChannel    = 0;
int servoChannel  = 2;
int pwmFreq       = 5000;
int servoFreq     = 50;
int pwmResolution = 8;

// ============================================================
// DEADZONE
// same value as remote so behavior is consistent
// ============================================================
float deadzone = 0.025;

// ============================================================
// CURRENT MODE
// tracks the mode sent from the remote in each packet
// sensors only take measurements when currentMode == 2
// ============================================================
int currentMode = 1;
int prevCarMode = 1;   // NEW - tracks previous mode so we can detect leaving mode 2

// ============================================================
// SEMI-AUTO (MODE 2) TUNING CONSTANTS
// adjust these on hardware - see notes at the bottom of the reply
// ============================================================
const int   IR_BLACK_VALUE        = HIGH;   // flip to LOW if steering nudges the wrong way
const int   TOF_SLOWDOWN_START_MM = 400;    // start slowing down under this distance
const int   TOF_HARD_STOP_MM      = 100;    // hard stop at/under this distance
const int   AUTO_STEER_NUDGE      = 2;      // servo duty nudge per cycle when off-line
const float AUTO_SPEED_STEP       = 0.02f;  // how fast auto speed ramps up/down per cycle

// Dynamic ToF braking:
// 100% speed needs 1700 mm to stop, plus a 50 mm safety buffer.
const float TOF_MAX_STOP_DISTANCE_MM = 1700.0f;
const float TOF_SAFETY_BUFFER_MM    = 50.0f;
const int   TOF_CONFIRM_READS        = 3;

// CHANGED - two consecutive black readings from one sensor trigger
// a full steering correction that is held for 0.75 seconds.
const int AUTO_BLACK_CONFIRM_READS = 2;
const unsigned long AUTO_FULL_CORRECTION_MS = 750;

// Servo duty 19 is centered. 26 is about full right; 24 is about 35 degrees right.
const int AUTO_STEER_RIGHT_CORRECTION_DUTY = 24;

// ============================================================
// SEMI-AUTO (MODE 2) RUNTIME STATE
// ============================================================
bool  autoStoppedLine  = false;  // kept for telemetry compatibility; Mode 2 never stops for line reads
float autoCurrentSpeed = 0.0f;   // 0.0-1.0 ramped speed magnitude while in auto mode
int   autoServoDuty    = 19;     // current auto-mode steering position, starts centered


// Dynamic ToF braking state.
// Braking only starts after 3 unsafe reads and releases after 3 safe reads.
bool autoTofBraking = false;
int  autoTofUnsafeStreak = 0;
int  autoTofSafeStreak   = 0;





// CHANGED - remembers the full correction direction and its minimum hold time.
unsigned long autoFullCorrectionUntil = 0;
int autoFullCorrectionDuty = 19;


const bool ENABLE_TOF_SAFETY = true;  // false = ignore ToF for steering testing

// ============================================================
// AUTO STEERING RANGE
// full steering lock (matches mode 1's max range) - snaps here
// once a sensor confirms black 3 cycles in a row
// ============================================================
#define AUTO_STEER_CENTER_DUTY 19
#define AUTO_STEER_HALF_LEFT   13   // full left (was 16 for half-angle)
#define AUTO_STEER_HALF_RIGHT  26   // full right (was 23 for half-angle)





// ============================================================
// AUTO STEERING STREAK COUNTERS
// counts consecutive cycles each individual sensor has seen black.
// after two reads, steering uses the full correction angle for 0.75s.
// ============================================================
int autoLeftBlackStreak  = 0;
int autoRightBlackStreak = 0;

// ============================================================
// PACKET STRUCTURE
// must exactly match the remote control struct
// if these dont match, received data will be garbage
// armed / targetSpeed = NEW, appended at the end so nothing shifts
// ============================================================
struct ControlPacket {
  float normalizedY;   // motor speed  (-1.0 = full forward, 1.0 = full reverse)
  float normalizedX;   // steering     (-1.0 = full left,    1.0 = full right)
  int   mode;          // current mode sent from remote
  bool  armed;          // NEW - true once semi-auto cruise driving is armed
  float targetSpeed;    // NEW - 0.0-1.0 locked cruise speed while armed
};

// ============================================================
// SENSOR TELEMETRY STRUCTURE
// sent back to the remote using nRF24 ACK payloads
// this must exactly match the remote SensorTelemetry struct
// new fields appended at the end, same as ControlPacket
// ============================================================
struct SensorTelemetry {
  int   irLeft;
  int   irRight;
  int   tofMm;
  bool  tofValid;
  float currentSpeed;     // NEW - car's current ramped auto-drive speed (0.0-1.0)
  bool  leftOnLine;        // NEW - true if left IR sensor currently sees black
  bool  rightOnLine;        // NEW - true if right IR sensor currently sees black
  bool  slowing;           // NEW - true while ToF is proportionally slowing the car
  bool  stoppedObstacle;   // NEW - true while hard-stopped due to ToF distance
  bool  stoppedLine;       // NEW - true while latched-stopped due to both IR seeing black
  float tofThresholdMm;    // NEW - current computed stop-braking threshold, in mm
  int   tofStreak;         // NEW - consecutive reads counted toward the active streak
  bool  tofBraking;        // NEW - true if currently in the ToF braking state
};

// RF radio object
RF24 radio(RF_CE, RF_CSN);

// VL53L0X ToF sensor object
VL53L1X tof;

// address must match remote exactly
const byte address[6] = "00001";

ControlPacket packet;
SensorTelemetry sensorData;

int duty      = 0;
int servoDuty = 0;

// counter for debugging
int rxCount = 0;

// ============================================================
// SENSOR TIMING
// sensor readings are refreshed every 50ms
// latest values are queued into nRF24 ACK payloads
// so the remote can display them in mode 2
// ============================================================
unsigned long lastSensorUpdate = 0;
const unsigned long sensorInterval = 50;

bool tofReady = false;

// ============================================================
// STOP CAR
// sets motor output to neutral
// used whenever packet values are in the deadzone
// ============================================================
void stopCar() {
  digitalWrite(IN1pin, LOW);
  digitalWrite(IN2pin, LOW);
  ledcWriteChannel(PWMChannel, 0);
}

// ============================================================
// UPDATE AUTO DRIVE
// runs the Mode 2 IR steering correction + ToF sensor logic
// called every time a packet is received while currentMode == 2
// reads IR fresh every call (ToF is refreshed on its own timer by
// updateSensors()), drives the motor/servo directly, and fills in
// the telemetry fields the remote uses for the driving screen
// ============================================================
void updateAutoDrive() {
  bool leftBlack  = (digitalRead(IR_LEFT_PIN)  == IR_BLACK_VALUE);
  bool rightBlack = (digitalRead(IR_RIGHT_PIN) == IR_BLACK_VALUE);
  unsigned long now = millis();

  // CHANGED - Mode 2 never stops because of black line readings.
  autoStoppedLine = false;

  // CHANGED - one single-sensor black read triggers correction.
  // The correction stays active for a full second even after the sensor clears.
  if (packet.armed) {
    if (now < autoFullCorrectionUntil) {
      // Keep the last full correction angle for one second.
      autoServoDuty = autoFullCorrectionDuty;
    } else if (leftBlack && !rightBlack) {
      // Keep your existing left-side full correction: about 45 degrees.
      autoServoDuty = AUTO_STEER_HALF_LEFT;
      autoFullCorrectionDuty = AUTO_STEER_HALF_LEFT;
      autoFullCorrectionUntil = now + AUTO_FULL_CORRECTION_MS;
    } else if (rightBlack && !leftBlack) {
      // CHANGED - right-side correction is about 35 degrees, not 45.
      autoServoDuty = AUTO_STEER_RIGHT_CORRECTION_DUTY;
      autoFullCorrectionDuty = AUTO_STEER_RIGHT_CORRECTION_DUTY;
      autoFullCorrectionUntil = now + AUTO_FULL_CORRECTION_MS;
    } else if (!leftBlack && !rightBlack) {
      // No line detected and the one-second correction has finished:
      // gently return to center.
      if (autoServoDuty > AUTO_STEER_CENTER_DUTY) autoServoDuty--;
      else if (autoServoDuty < AUTO_STEER_CENTER_DUTY) autoServoDuty++;
    }
  } else {
    autoServoDuty = AUTO_STEER_CENTER_DUTY;
    autoFullCorrectionUntil = 0;
    autoFullCorrectionDuty = AUTO_STEER_CENTER_DUTY;
  }

  autoServoDuty = constrain(autoServoDuty, AUTO_STEER_HALF_LEFT, AUTO_STEER_HALF_RIGHT);
  // ToF: figure out how much the obstacle should scale down our allowed speed
  // ============================================================
  // DYNAMIC ToF BRAKING
  //
  // At full speed, stopping distance is 1700 mm.
  // At any lower current speed, stopping distance scales linearly:
  //
  // stoppingDistance = 1700 mm * currentSpeedMagnitude
  //
  // A 50 mm safety buffer is added. Three unsafe readings begin
  // braking; three safe readings allow acceleration again.
  //
  // NEW - tofThresholdMm and tofStreak are reported back to the
  // remote every cycle so the driving screen can show the live
  // trigger distance and how many consecutive reads are in the
  // currently-active streak.
  // ============================================================
  bool  stoppedObstacle = false;
  bool  slowing         = false;
  float allowedSpeed    = 0.0f;
  float tofThresholdMm  = 0.0f;
  int   tofStreak       = 0;

  if (packet.armed) {
    float targetSpeed = constrain(packet.targetSpeed, -1.0f, 1.0f);
    float targetMagnitude = fabsf(targetSpeed);
    float targetDirection = targetSpeed >= 0.0f ? 1.0f : -1.0f;

    // Normally we are allowed to work toward the selected target speed.
    float allowedMagnitude = targetMagnitude;

    if (ENABLE_TOF_SAFETY && sensorData.tofValid) {
      float currentMagnitude = fabsf(autoCurrentSpeed);

      // Example:
      // at 100%: 1700 + 50 = 1750 mm
      // at 50%:   850 + 50 = 900 mm
      tofThresholdMm =
        (TOF_MAX_STOP_DISTANCE_MM * currentMagnitude) +
        TOF_SAFETY_BUFFER_MM;

      bool obstacleTooClose = sensorData.tofMm <= tofThresholdMm;

      if (!autoTofBraking) {
        // Need three consecutive unsafe readings before braking.
        if (obstacleTooClose) {
          autoTofUnsafeStreak++;
          autoTofSafeStreak = 0;

          if (autoTofUnsafeStreak >= TOF_CONFIRM_READS) {
            autoTofBraking = true;
            autoTofUnsafeStreak = 0;
          }
        } else {
          autoTofUnsafeStreak = 0;
        }
      } else {
        // Already braking: need three consecutive safe readings
        // before accelerating toward the target again.
        if (obstacleTooClose) {
          autoTofSafeStreak = 0;
        } else {
          autoTofSafeStreak++;

          if (autoTofSafeStreak >= TOF_CONFIRM_READS) {
            autoTofBraking = false;
            autoTofSafeStreak = 0;
          }
        }
      }

      // NEW - report whichever streak is currently "live": the
      // unsafe streak while approaching the trigger, or the safe
      // streak while braking and waiting to release.
      tofStreak = autoTofBraking ? autoTofSafeStreak : autoTofUnsafeStreak;

      if (autoTofBraking) {
        // Work out the maximum safe speed from the current distance.
        // Example: 900 mm distance:
        // (900 - 50) / 1700 = 0.50, so maximum safe speed is 50%.
        float safeMagnitude =
          (sensorData.tofMm - TOF_SAFETY_BUFFER_MM) /
          TOF_MAX_STOP_DISTANCE_MM;

        safeMagnitude = constrain(safeMagnitude, 0.0f, 1.0f);

        // Never exceed the selected target, but slow if required.
        allowedMagnitude = fmin(targetMagnitude, safeMagnitude);
        slowing = allowedMagnitude < targetMagnitude;

        if (allowedMagnitude <= 0.01f) {
          stoppedObstacle = true;
        }
      }
    } else if (!ENABLE_TOF_SAFETY) {
      // ToF intentionally disabled: clear old braking state.
      autoTofBraking = false;
      autoTofUnsafeStreak = 0;
      autoTofSafeStreak = 0;
    }

    allowedSpeed = targetDirection * allowedMagnitude;
  } else {
    // Reset ToF braking when Mode 2 is disarmed.
    autoTofBraking = false;
    autoTofUnsafeStreak = 0;
    autoTofSafeStreak = 0;
  }

      // ============================================================
  // SPEED RAMPING
  // Steps autoCurrentSpeed toward allowedSpeed by AUTO_SPEED_STEP
  // each cycle instead of jumping instantly. This was missing -
  // without it, autoCurrentSpeed never left 0, so the ToF threshold
  // (which scales off actual current speed) never left 50mm
  // (just the safety buffer), and the car never actually reached
  // its target speed either.
  // ============================================================
  if (autoCurrentSpeed < allowedSpeed) {
    autoCurrentSpeed = fmin(autoCurrentSpeed + AUTO_SPEED_STEP, allowedSpeed);
  } else if (autoCurrentSpeed > allowedSpeed) {
    autoCurrentSpeed = fmax(autoCurrentSpeed - AUTO_SPEED_STEP, allowedSpeed);
  }

  // CHANGED - match Mode 1 convention:
  // negative = physical forward, positive = physical reverse. 
  if (autoCurrentSpeed < -0.01f) {
    digitalWrite(IN1pin, HIGH );
    digitalWrite(IN2pin, LOW);                   
    ledcWriteChannel(PWMChannel, (int)(-autoCurrentSpeed * 255));
  } else if (autoCurrentSpeed > 0.01f) {
    digitalWrite(IN1pin, LOW);
    digitalWrite(IN2pin, HIGH);
    ledcWriteChannel(PWMChannel, (int)(autoCurrentSpeed * 255));
  } else {
    stopCar();
  }

  ledcWriteChannel(servoChannel, autoServoDuty);

  // fill in the telemetry fields the remote's driving screen reads
  sensorData.currentSpeed    = autoCurrentSpeed;
  sensorData.leftOnLine      = rightBlack;
  sensorData.rightOnLine     = leftBlack;
  sensorData.slowing         = slowing;
  sensorData.stoppedObstacle = stoppedObstacle;
  sensorData.stoppedLine     = false;  // Mode 2 never stops for the line
  sensorData.tofThresholdMm  = tofThresholdMm;   // NEW
  sensorData.tofStreak       = tofStreak;        // NEW
  sensorData.tofBraking      = autoTofBraking;   // NEW
}

// ============================================================
// UPDATE SENSOR READINGS
// reads both IR sensors and the VL53L0X distance
// then loads the newest values into the nRF24 ACK payload
// only takes measurements when currentMode == 2
// ============================================================
void updateSensors() {
  if (currentMode == 2) {
    sensorData.irLeft  = digitalRead(IR_LEFT_PIN);
    sensorData.irRight = digitalRead(IR_RIGHT_PIN);

    if (tofReady) {
      int distance = tof.read();

      if (!tof.timeoutOccurred()) {
        sensorData.tofMm = distance;
        sensorData.tofValid = true;
      } else {
        sensorData.tofMm = -1;
        sensorData.tofValid = false;
      }
    } else {
      sensorData.tofMm = -1;
      sensorData.tofValid = false;
    }
  }

    // --- DEBUG: live ToF distance measurement ---
  // prints the VL53L0X reading every time updateSensors() runs
  //Serial.printf("TOF Distance: %d mm    Valid: %s\n",
                //sensorData.tofMm,
                //sensorData.tofValid ? "YES" : "NO");

  radio.writeAckPayload(1, &sensorData, sizeof(sensorData));
}
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
void loop() {

  unsigned long currentTime = millis();

  // update sensor readings on a timed interval
  // this keeps telemetry fresh without blocking motor control
  if (currentTime - lastSensorUpdate >= sensorInterval) {
    lastSensorUpdate = currentTime;
    updateSensors();
  }

  // check if a packet arrived from the remote
  if (radio.available()) {

    // read packet bytes into our struct
    radio.read(&packet, sizeof(packet));
    rxCount++;

    // update current mode from the packet
    currentMode = packet.mode;

    // if we've just left mode 2, reset all auto-drive state so a
    // fresh entry into mode 2 later starts from a clean slate
    if (packet.mode != prevCarMode) {
      if (packet.mode != 2) {
        autoStoppedLine  = false;
        autoCurrentSpeed = 0.0f;
        autoServoDuty    = 19;
        autoLeftBlackStreak  = 0;
        autoRightBlackStreak = 0;

      // reset the 0.75-second full-correction timer too
        autoFullCorrectionUntil = 0;
        autoFullCorrectionDuty = AUTO_STEER_CENTER_DUTY;


        sensorData.currentSpeed    = 0.0f;
        sensorData.leftOnLine      = false;
        sensorData.rightOnLine     = false;
        sensorData.slowing         = false;
        sensorData.stoppedObstacle = false;
        sensorData.stoppedLine     = false;
        sensorData.tofThresholdMm  = 0.0f;   // NEW
        sensorData.tofStreak       = 0;      // NEW
        sensorData.tofBraking      = false;  // NEW
      }
      prevCarMode = packet.mode;
    }

    // queue newest sensor readings for the next ACK response
    radio.writeAckPayload(1, &sensorData, sizeof(sensorData));

    if (currentMode == 2) {
      // ============================================================
      // SEMI-AUTO MODE 2
      // fully autonomous - ignores packet.normalizedY/X, drives itself
      // off IR line sensors + ToF distance instead
      // ============================================================
      updateAutoDrive();
    }
    else {
      // ============================================================
      // MOTOR CONTROL
      // convert normalizedY into PWM duty cycle and direction signal
      // cubic curve gives exponential feel - small inputs = small response
      // large inputs = large response, much more natural to drive
      // ENA = PWM speed, IN1+IN2 = direction
      // ============================================================
      duty = abs(packet.normalizedY * packet.normalizedY) * 255;

      if (packet.normalizedY < -deadzone) {
        // forward - IN1 HIGH, IN2 LOW, PWM on
        digitalWrite(IN1pin, HIGH);
        digitalWrite(IN2pin, LOW);
        ledcWriteChannel(PWMChannel, duty);
      }
      else if (packet.normalizedY > deadzone) {
        // reverse - IN1 LOW, IN2 HIGH, PWM on
        digitalWrite(IN1pin, LOW);
        digitalWrite(IN2pin, HIGH);
        ledcWriteChannel(PWMChannel, duty);
      }
      else {
        // deadzone - stop motor completely
        stopCar();
      }

      // ============================================================
      // SERVO CONTROL
      // convert normalizedX into servo PWM duty cycle
      // 8 bit servo duty range: 13 = 0deg (right), 26 = 180deg (left)
      // center = ~19-20 = 90deg
      // ============================================================
      if (abs(packet.normalizedX) <= deadzone) {
        // centered - hold middle position
        servoDuty = 19;
      }
      else {
        // map -1.0 to 1.0 into servo duty range 13 to 26
        servoDuty = (int)(13 + (packet.normalizedX + 1.0) * 6.5);
        servoDuty = constrain(servoDuty, 13, 26);
      }

      ledcWriteChannel(servoChannel, servoDuty);
    }

    // --- DEBUG: raw received packet values ---
    //Serial.printf("Received  Motor: %.3f    Steering: %.3f\n", packet.normalizedY, packet.normalizedX);

    // --- DEBUG: sensor telemetry ---
    //Serial.printf("IR L: %d    IR R: %d    TOF: %d mm    Valid: %s\n",
                  //sensorData.irLeft,
                  //sensorData.irRight,
                  //sensorData.tofMm,
                  //sensorData.tofValid ? "YES" : "NO");

    // --- DEBUG: total packets received ---
    //Serial.printf("Packets received: %d\n", rxCount);
  }
}

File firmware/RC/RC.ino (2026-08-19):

#include <SPI.h>
#include <nRF24L01.h>
#include <RF24.h>
#include <TFT_eSPI.h>

// ============================================================
// PIN DEFINITIONS
// ============================================================
#define joystickPinX 35   // joystick X axis analog input
#define joystickPinY 34   // joystick Y axis analog input
#define joystickSW   32   // joystick button (SW) - triggers animation replay
                          // wire: SW -> pin 32, GND -> GND
                          // uses internal pull-up so no resistor needed

#define RF_CE  27         // controls radio mode (transmit vs listen)
#define RF_CSN 25         // SPI chip select, tells ESP32 to talk to radio
#define RF_SCK 14         // SPI clock, synchronizes communication timing
#define RF_MO  13         // MOSI, ESP32 sends data TO radio
#define RF_MI  26         // MISO, radio sends data back TO ESP32

// ============================================================
// MODE BUTTON + LED PIN DEFINITIONS
// based on the schematic:
//
// SW1:
//   button input = GPIO19, uses internal pull-up
//   LED output   = GPIO15 through resistor to LED to GND
//
// SW2:
//   button input = GPIO21, uses internal pull-up
//   LED output   = GPIO33 through resistor to LED to GND
//
// SW3:
//   button input = GPIO22, uses internal pull-up
//   LED output   = GPIO12 through resistor to LED to GND
// ============================================================
#define MODE1_BUTTON 19   // SW1 - RC mode button
#define MODE2_BUTTON 21   // SW2 - semi-auto mode button
#define MODE3_BUTTON 22   // SW3 - AI mode button

#define MODE1_LED    15   // LED for RC mode
#define MODE2_LED    33   // LED for semi-auto mode
#define MODE3_LED    12   // LED for AI mode

// ============================================================
// MODE DEFINITIONS
// MODE_RC is the default mode when the remote starts
// MODE_SEMI_AUTO now drives the car (see below)
// MODE_AI does nothing for now except light its LED
// only MODE_RC runs the normal joystick driving code
// ============================================================
#define MODE_RC        1
#define MODE_SEMI_AUTO 2
#define MODE_AI        3

int currentMode = MODE_RC;   // remote starts in normal RC car mode

// ============================================================
// MODE BUTTON DEBOUNCE
// these buttons are wired to GND and use ESP32 internal pull-ups
// HIGH = not pressed
// LOW  = pressed
// each button has its own stable state, last raw reading, and timer
// ============================================================
const int modeButtonPins[3] = { MODE1_BUTTON, MODE2_BUTTON, MODE3_BUTTON };
const int modeLedPins[3]    = { MODE1_LED,    MODE2_LED,    MODE3_LED };

bool modeLastReading[3] = { HIGH, HIGH, HIGH };
bool modeButtonState[3] = { HIGH, HIGH, HIGH };
bool modeLastState[3]   = { HIGH, HIGH, HIGH };
unsigned long modeLastDebounceTime[3] = { 0, 0, 0 };

const unsigned long modeDebounceDelay = 50;  // 50ms debounce window

// ============================================================
// JOYSTICK CALIBRATION
// center values are the resting position of the joystick
// ============================================================
int joystickCenterY = 1925;
int joystickCenterX = 1875;

// ============================================================
// DEADZONE
// joystick must move this far from center before anything happens
// prevents drift from imperfect joystick centering
// ============================================================
float deadzone = 0.025;

// ============================================================
// SLEW RATE
// instead of jumping instantly to target speed, we step toward it
// this prevents mechanical stress and feels more natural to drive
// sameDirectionStep = how fast we accelerate/decelerate same direction
// oppDirectionStep  = how fast we transition through zero when reversing
// ============================================================
float currentNormalizedY = 0;    // current motor speed, starts at rest
float sameDirectionStep = 0.015; // 0 to full speed in ~200ms
float oppDirectionStep  = 0.008; // reversal through zero in ~375ms

// ============================================================
// TIMING
// we dont recalculate every single loop iteration
// motor slew runs every 3ms, steering + RF send runs every 50ms
// semi-auto screen updates + RF send every 50ms too
// ============================================================
unsigned long lastMotorUpdate = 0;
unsigned long lastServoUpdate = 0;
unsigned long lastAutoUpdate  = 0;
const unsigned long motorInterval = 3;
const unsigned long servoInterval = 50;
const unsigned long autoInterval  = 50;

// ============================================================
// PACKET STRUCTURE
// this is exactly what gets sent over RF to the car every 50ms
// normalizedY = motor speed  (-1.0 = full reverse, 1.0 = full forward)
// normalizedX = steering     (-1.0 = full left,    1.0 = full right)
// mode        = current remote mode, so the car knows when to run sensors
// armed       = NEW - true once semi-auto cruise driving has been armed
// targetSpeed = NEW - 0.0-1.0 locked cruise speed while armed
// ============================================================
struct ControlPacket {
  float normalizedY;
  float normalizedX;
  int   mode;
  bool  armed;
  float targetSpeed;
};

// ============================================================
// SENSOR TELEMETRY STRUCTURE
// this comes BACK from the car using nRF24 ACK payloads
// must match the car-side SensorTelemetry struct exactly
//
// irLeft / irRight:
//   digital values from the two TCRT5000 IR reflection sensors
//
// tofMm:
//   VL53L0X distance measurement in millimeters
//
// tofValid:
//   true  = ToF reading is valid
//   false = ToF reading failed / sensor not found / timeout
//
// currentSpeed / leftOnLine / rightOnLine / slowing / stoppedObstacle / stoppedLine:
//   semi-auto driving status reported back by the car each cycle
//
// tofThresholdMm / tofStreak / tofBraking:
//   NEW - live ToF braking debug info reported back by the car each
//   cycle: the current computed stop-trigger distance in mm, how
//   many consecutive reads are in the currently-active streak, and
//   whether the car is currently in the braking state.
// ============================================================
struct SensorTelemetry {
  int   irLeft;
  int   irRight;
  int   tofMm;
  bool  tofValid;
  float currentSpeed;
  bool  leftOnLine;
  bool  rightOnLine;
  bool  slowing;
  bool  stoppedObstacle;
  bool  stoppedLine;
  float tofThresholdMm;
  int   tofStreak;
  bool  tofBraking;
};

SensorTelemetry sensorData = { 0, 0, -1, false, 0.0f, false, false, false, false, false, 0.0f, 0, false };

// RF radio object using CE and CSN pins
RF24 radio(RF_CE, RF_CSN);

// SPI for Display
TFT_eSPI tft = TFT_eSPI();

// address - both radios must match exactly
const byte address[6] = "00001";
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
